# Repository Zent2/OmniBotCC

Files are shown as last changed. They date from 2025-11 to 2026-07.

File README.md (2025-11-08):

# OmniBotCC — Robotat Omnidirectional Agent

**Overview**  
OmniBotCC is a complete project (firmware, MATLAB utilities and Python client) for an **omnidirectional mobile platform** designed to operate inside the **Robotat** ecosystem at the *Universidad del Valle de Guatemala*. The repository provides a reproducible toolset for control experiments, trajectory planning and tracking, simulation, and teaching.

---

## Repository layout (high-level)

- `ESP32/` — ESP32 firmware (ESP-IDF): closed-loop control of 4 stepper motors, AS5600 encoder readings (ADC), per-motor PID and UDP communication.  
- `Funciones_Matlab/` — MATLAB scripts and functions for trajectory planning, Robotat connection, simulation, visualization, calibration and data analysis.  
- `Funciones_Python/` — Python tools and example scripts for sending UDP commands to the ESP32 and quick demos.  
---

## Key features

- Closed-loop PID speed control for four stepper motors (one PID per motor).  
- AS5600 magnetic encoder feedback using ADC for angle and speed estimation.  
- UDP-based command & telemetry over Wi-Fi (integrates with Robotat server).  
- Timer-based step generation with configurable microstepping (example: up to 1/32).  
- FreeRTOS-based multitasking (encoder sampling ISR, PID task, motor control task).  
- MATLAB toolset for trajectory generation, Robotat integration, calibration and post-processing.  
- Python client for quick demos and automation.

---

## System architecture (summary)

**Core components**

- **ESP32 MCU** — main controller: RTOS tasks, PID loops, UDP server.  
- **Stepper drivers** — accept STEP/DIR signals per wheel.  
- **AS5600 encoders** — analog outputs read by ADC for angular position.  
- **PC (MATLAB / Python)** — trajectory planning, visualization and commanding.

**Control loop (stepper motors)**

1. Encoder sampling via timer ISR (example: every 50 ms → 20 Hz).  
2. Compute angular difference → estimate RPM per motor.  
3. PID task computes correction (setpoint vs measured RPM).  
4. Motor control task updates timer parameters and generates STEP pulses.  
5. UDP interface accepts textual commands to change setpoints and states in real time.

### Control loop (Robot)

The closed-loop control for the omnidirectional robot is executed in MATLAB, using real-time feedback from **Robotat** to track the platform’s position and orientation while commanding velocities via UDP.  
The process runs in a control loop with sampling time `dt` (typically 50–100 ms) and includes the following stages:

1. **Pose acquisition (feedback):**  
   The current robot pose (`x_real`, `y_real`, `θ_real`) is obtained from the Robotat system using the function `robotat_get_pose()`.  
   The data is corrected by a known offset and converted to meters and radians.

2. **Goal selection (lookahead target):**  
   The controller selects the next goal point along the trajectory using a *lookahead distance* criterion.  
   This ensures smooth progression between waypoints and avoids oscillations when the robot is close to intermediate targets.

3. **Error computation:**  
   The position and orientation errors are calculated as:  
   \[
   e = \begin{bmatrix} x_g - x \\ y_g - y \\ \theta_g - \theta \end{bmatrix}
   \]
   where \( (x_g, y_g, \theta_g) \) is the current goal pose.  
   These errors drive the PI controller and determine the corrective velocities.

4. **Feedforward + PI control law:**  
   The desired linear and angular velocities are estimated from consecutive points in the trajectory (`v_des`, `w_des`).  
   A **Feedforward + PI** scheme computes the commanded velocity vector in the world frame:
   \[
   \dot{q}_{world} = \dot{q}_{d,world} + K_p e + K_i \int e\,dt
   \]
   where `Kp` and `Ki` are tuned empirically.  
   Integrator limits prevent windup (`I_min`, `I_max`).

5. **Transformation to body frame:**  
   The commanded velocities are converted from the world frame to the robot’s local frame using the current orientation `θ`:
   \[
   v_{body} = R(θ)^T \begin{bmatrix} v_x \\ v_y \end{bmatrix}
   \]
   forming the body velocity vector:
   \[
   V_b = \begin{bmatrix} ω \\ v_{bx} \\ v_{by} \end{bmatrix}
   \]

6. **Wheel speed conversion and saturation:**  
   Wheel angular velocities are obtained via:
   \[
   ω_{wheels} = \frac{1}{r} H_0 V_b
   \]
   where `r` is the wheel radius and `H₀` the kinematic matrix of the omnidirectional platform.  
   These are converted to RPM and limited by `rpm_max`.  
   If saturation occurs, the integrator is frozen (anti-windup).

7. **Command transmission (actuation):**  
   The computed wheel RPMs are sent to the physical robot via the UDP interface using:
   ```matlab
   robot_set_velocities(u_rpm);

---

## Example UDP commands

- `start` — enable all motors  
- `stop` — disable all motors  
- `m0_rpm=250` — set motor 0 target to 250 RPM  
- `m1_dir=CW` / `m1_dir=CCW` — set motor 1 direction  
- `m2_start` / `m3_stop` — control individual motors

---

## Default hardware configuration (example)

**Pin mapping (example)**

| Component | GPIOs | Notes |
|---|---:|---|
| Enable (drivers) | 23 | Shared enable for all drivers |
| STEP (m0..m3) | 26, 19, 16, 14 | Step pulses for motors 0–3 |
| DIR (m0..m3) | 25, 18, 4, 27 | Direction pins for motors 0–3 |
| AS5600 ADC inputs | 34, 35, 32, 33 | Analog encoder inputs |
| Wi-Fi status LED | 2 | Connection status indicator |

**Motor parameters (examples)**

- Steps per revolution: 200  
- Microstepping: 1/32 (configurable)  
- Approx. maximum RPM: ~400  
- Example PID starting gains (tune on hardware): `Kp = 0.04, Ki = 0.002, Kd = 0.0002`
---

## Build & flash (firmware)

1. Install ESP-IDF toolchain (recommended: ESP-IDF v5.x). Follow Espressif's official instructions.  
2. Clone this repository.  
3. From the `firmware/` folder run:

```bash
idf.py set-target esp32
idf.py build
idf.py flash
idf.py monitor
```

---

## MATLAB overview

The `matlab/` folder contains:

- Robotat connection utilities (`robotat_connect`, `robotat_get_pose`, etc.).
- Calibration and quick-start scripts (`Calibracion_Robot.m`, `Inicio_Rapido.m`).  
- Trajectory generators and visualization scripts (`Trayectoria_Omnidireccional.m`, `Trayectorias_Mapa.m`).  
- Utilities for pose conversions and data logging.

Use `Inicio_Rapido.m` to start experiments and `Trayectoria_Omnidireccional.m` for trajectory execution and analysis.

---

## Python client

The `python/` folder includes:

- `Inicio_Rapido.py` — demo routines with connect, set velocities, start/stop and example motion sequences.  
- `udp_robot.py` — helper functions: `robot_connect`, `robot_disconnect`, `robot_start`, `robot_stop`, `robot_set_velocities`.  

Requirements: Python 3.8+, `numpy` (see `requirements.txt`).

---

## License & attribution

This project is property of **Universidad del Valle de Guatemala**. Contact them for licensing and distribution permissions.

---

## Author

**Author:** Christian Campos  
**Institution:** Universidad del Valle de Guatemala

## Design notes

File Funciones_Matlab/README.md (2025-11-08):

# <span style="color:rgb(213,80,0)">OmniBotCC – MATLAB Project Documentation</span>

This Live Script provides an overview of the **OmniBotCC** MATLAB environment,

used for trajectory generation, robot control, and pose tracking with

the **Robotat** motion capture system.

The project communicates with an omnidirectional mobile robot equipped

with a ESP32 microcontroller and integrates MATLAB for simulation, closed loop control,

trajectory planning and performance evaluation.

**Author**: Christian Campos

**Date:** October 2025  

# Project Overview

This MATLAB workspace contains all the scripts and functions needed for:

-   Establishing communication with the omnidirectional robot via Wi-Fi. 
-   Tracking and recording the robot’s pose using the Robotat system. 
-   Generating and executing pre-defined and planed trajectories. 
-   Visualizing, calibrating, and analyzing system performance. 

 The workflow typically follows this sequence:

1.   Connection.
2. Trajectory Generation
3. Trajectory Execution or Marker Tracking in closed loop
4. Data Visualization and Error Analysis

#  Directory Structure

 | `/Simulaciones` | Folder | Simulation models and test scenarios |

 | `/slprj` | Folder | Auto-generated Simulink project files |

 | `Calibracion_Robot.m` | Script | Calibrates the robot’s position and angle (yaw) |

 | `genmap.m` | Script | Generates a Robotat map for trajectory planning |

 | `Inicio_Rapido.m` | Script | Quick Start |

  | `Offsets.mat` | Data | Pre-saved position offsets from Robotat calibration |

  | `q2eul.m`, `q2rot.m` | Functions | Convert quaternions to Euler angles or rotation matrices |

 | `robotat_connect.m` | Function | Connects to the Robotat motion capture server |

 | `robotat_disconnect.m` | Function | Ends connection with Robotat |

 | `robotat_get_pose.m` | Function | Retrieves the current robot pose from Robotat |

 | `robotat_trvisualize.m` | Function | Visualizes rigid bodies within the Robotat reference frame |

 | `robot_connect.m` | Function | Establishes communication with the robot controller |

 | `robot_disconnect.m` | Function | Closes communication with the robot |

 | `robot_emergency_stop.m` | Function | Immediately halts robot movement |

 | `robot_send_WiFi.m` | Function | Sends data packets to the robot over Wi-Fi |

 | `robot_set_ustep.m` | Function | Sets the microstepping configuration for motors | (NOT USED)

 | `robot_set_velocities.m` | Function | Sends velocity commands to each wheel |

 | `robot_start.m` / `robot_stop.m` | Functions | Start/stop robot motion commands |

 | `Trayectoria_Omnidireccional.m` | Script | Omnidirectional trajectory generation and execution module |

 | `Trayectorias_Mapa.m` | Script | Builds and visualizes a trajetory over a map with obstacles|

 | `Seguimiento_marcador.m` | Script | Follow a markers' position |

#  Simulation Environment

 The `/Simulaciones` folder includes models and scripts for testing

 the robot control algorithms in a simulated environment before

 applying them to the real hardware.

#  License

 This project is property of Universidad del Valle de Guatemala.

```matlab
mdfile = export("README.mlx",Format="markdown")
```

```TextOutput
mdfile = 'C:\Users\chris\OneDrive - UVG\UVG-ChrisLaptop\Proyecto de Graduacion-Tesis\Carpeta Final\Funciones_Matlab\README.md'
```

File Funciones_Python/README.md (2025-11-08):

# OmniBotCC (Python)

Example project to control an OmniBotCC robot over UDP (ESP32) and demonstrate mapping body velocities to wheel RPMs.

## Repository contents
- `Inicio Rapido.py`  
    Main script with two demos:
    - `simple_demo()` — basic commands (connect, set velocities, start/stop, disconnect) and a sequential RPM motion routine.
    - `vb_demo()` — maps body velocities Vb = [omega, vx, vy] to the 4-wheel RPMs using matrix H0 and controls the robot via UDP.
- `udp_robot.py`  
    UDP module with functions:
    - `robot_connect()` — creates a UDP socket and configures the ESP32 IP/port.
    - `robot_disconnect()` — closes the socket.
    - `robot_start()` / `robot_stop()` — sends `start`/`stop` commands.
    - `robot_set_velocities(rpm_vector)` — sends direction and RPM per motor (`m{i}_dir`, `m{i}_rpm`).
- `robotat.py`  
    Simple TCP connection example (placeholder) with:
    - `robotat_connect()` — attempts a TCP connection to a host/port.
    - `robotat_disconnect(tcp_obj)` — closes the TCP connection.

## Requirements
- Python 3.8+
- numpy
- Standard modules: socket, time, math

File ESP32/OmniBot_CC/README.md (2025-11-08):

# Robotat Omnidirectional Agent (OmniBotCC)

## Overview
**OmniBotCC** is an embedded control application developed using the **ESP-IDF framework** for the **ESP32 microcontroller**. It serves as the main controller for an **omnidirectional robotic agent** within the **Robotat ecosystem** at *Universidad del Valle de Guatemala*.

The system controls **four stepper motors** arranged in an omnidirectional configuration, allowing movement across a 2D plane. Each motor is equipped with an **AS5600 magnetic encoder** for closed-loop feedback, enabling precise **PID speed control**. Communication with the Robotat environment is established via **UDP over Wi-Fi**, allowing external systems (e.g., Robotat server) to send commands and receive updates.

---

## Main Features
- Closed-loop control of four stepper motors using PID.
- High-resolution feedback from AS5600 encoders (ADC-based angle measurement).
- UDP communication for remote control and data exchange.
- Timer-based PWM generation for stepper control (microstepping up to 1/32).
- Wi-Fi initialization with optional LED status indicator.
- Multi-tasking architecture using FreeRTOS:
  - Timer-based periodic callback (20 Hz) for encoder sampling.
  - PID task for closed-loop speed regulation.
  - Motor control task for stepper pulse generation.
- Dynamic command parsing via UDP or UART (optional).
- Robust error handling and logging through ESP-IDF’s `esp_log`.

---

## System Architecture

### Core Components
| Component | Description |
|---|---|
| ESP32 MCU | Central controller executing FreeRTOS tasks and PID loops. |
| Stepper Drivers | Receive STEP/DIR signals for motion control. |
| AS5600 Encoders | Provide analog angular position feedback for speed estimation. |
| Wi-Fi UDP Server | Handles incoming motion and configuration commands. |
| PID Controller | Regulates motor speed using feedback from encoders. |

---

## Control Loop Description

1. **Encoder Sampling (Timer ISR)**  
   The system periodically reads angular positions from the AS5600 sensors every **50 ms (20 Hz)**.  
   Angular differences are converted into estimated RPM values per motor.

2. **PID Task**  
   The PID controller compares desired RPM vs. measured RPM to compute a control signal.  
   The signal adjusts the timer parameters that generate motor steps.

3. **UDP Command Interface**  
   Commands are received as strings through UDP packets. Examples include:
start
stop
m0_rpm=200
m1_dir=CCW
m2_start
m3_stop

Commands dynamically update the control parameters in real time.

4. **Motor Control**  
Each motor runs in closed-loop mode, maintaining its target speed with high precision.

---

## Command Examples

| Command | Description |
|---|---|
| `start` | Enables all motors. |
| `stop` | Disables all motors. |
| `m0_rpm=250` | Sets motor 0 to 250 RPM. |
| `m1_dir=CW` / `m1_dir=CCW` | Sets direction of motor 1. |
| `m2_start` | Activates motor 2 only. |
| `m3_stop` | Stops motor 3 only. |

---

## File Structure

```
OmniRobot_CC/
├─ platformio.ini
├─ README.md
├─ docs/
│  ├─ overview.md
│  └─ wiring.md
├─ firmware/
│  ├─ src/
│  │  ├─ main.cpp
│  │  ├─ MotorController.cpp
│  │  ├─ MotorController.h
│  │  ├─ PID.cpp
│  │  ├─ PID.h
│  │  ├─ AS5600.cpp
│  │  ├─ AS5600.h
│  │  ├─ WiFiManager.cpp
│  │  ├─ WiFiManager.h
│  │  ├─ WebServer.cpp
│  │  └─ config.h
│  ├─ lib/
│  └─ include/
├─ hardware/
│  ├─ schematics/
│  └─ pcb/
├─ tools/
│  ├─ calibrate.py
│  └─ bench_tests/
├─ data/
│  └─ spiffs/
├─ examples/
└─ releases/
    └─ firmware_v1.0.bin
```

---

## Hardware Configuration

### Pinout Summary
| Component | GPIOs | Description |
|---|---|---|
| Enable | 23 | Shared enable pin for all drivers |
| Stepper STEP Pins | 26, 19, 16, 14 | Pulse control for motors 0–3 |
| Stepper DIR Pins | 25, 18, 4, 27 | Direction control for motors 0–3 |
| AS5600 Inputs | 34, 35, 32, 33 | ADC inputs for encoder readings |
| LED (Wi-Fi) | 2 | Status indicator for Wi-Fi connection |

### Motor Parameters
- Steps per revolution: 200  
- Microstepping: 1/32  
- Maximum RPM: 400  
- PID gains (tunable):
Kp = 0.04
Ki = 0.002
Kd = 0.0002

---

## Build and Flash Instructions

1. **Set up ESP-IDF (v5.x)** following the official [ESP-IDF documentation](https://docs.espressif.com/).
2. Clone this repository.
3. Build the firmware: idf.py build
4. Flash the ESP32: idf.py flash
5. Monitor before using: idf.py monitor

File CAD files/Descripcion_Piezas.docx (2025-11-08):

Estas son las piezas del prototipo, por lo que los colores si importan (menos los que dicen preferiblemente). El color azul y el verde pino fueron colocados dentro de las compras de materiales del departamento.

Pieza | Descripción

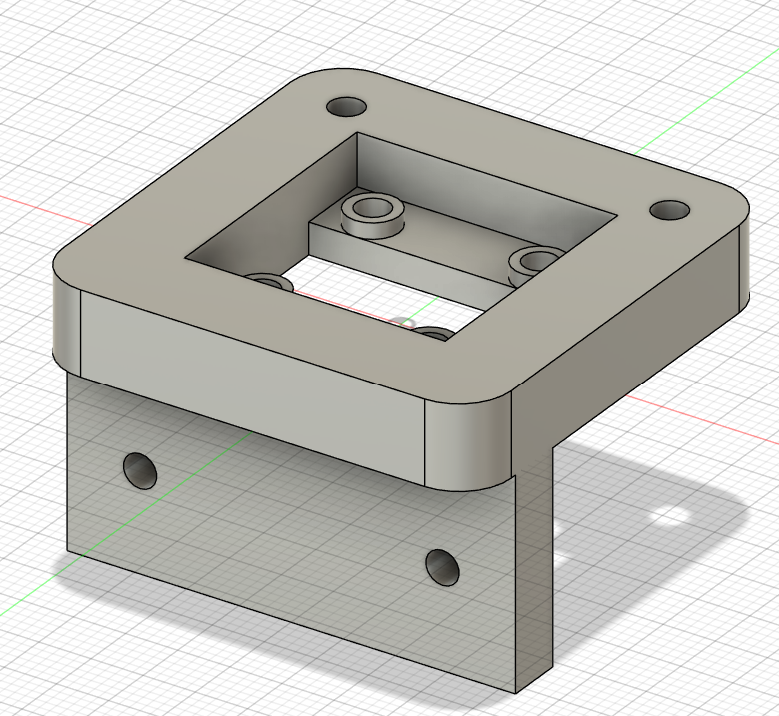
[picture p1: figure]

| Soporte AS5600_R_x2: Color: Negro (preferiblemente) Dimensiones Generales: 28x43x34 en mm Agujeros: 3 mm

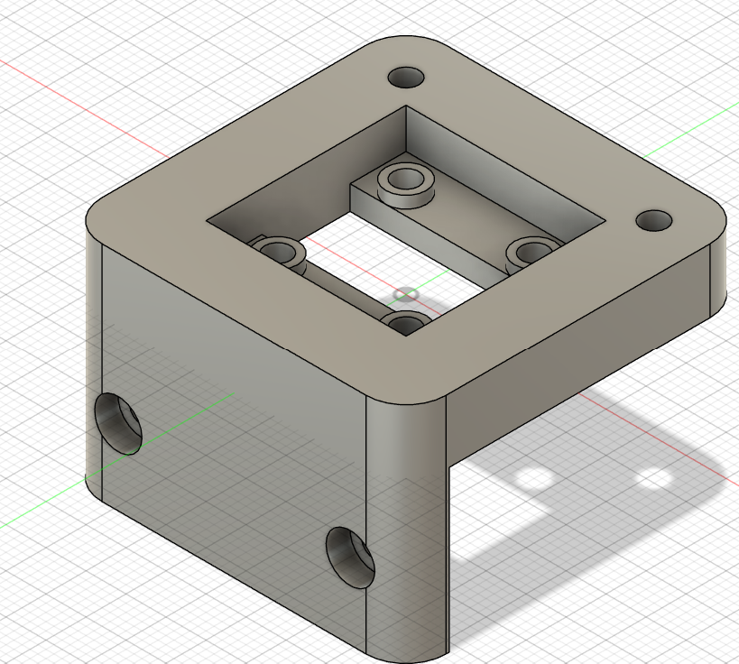
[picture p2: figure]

| Soporte AS5600_L_x2: Color: Negro (preferiblemente) Dimensiones Generales: 28x43x34 en mm Agujeros: 3 mm

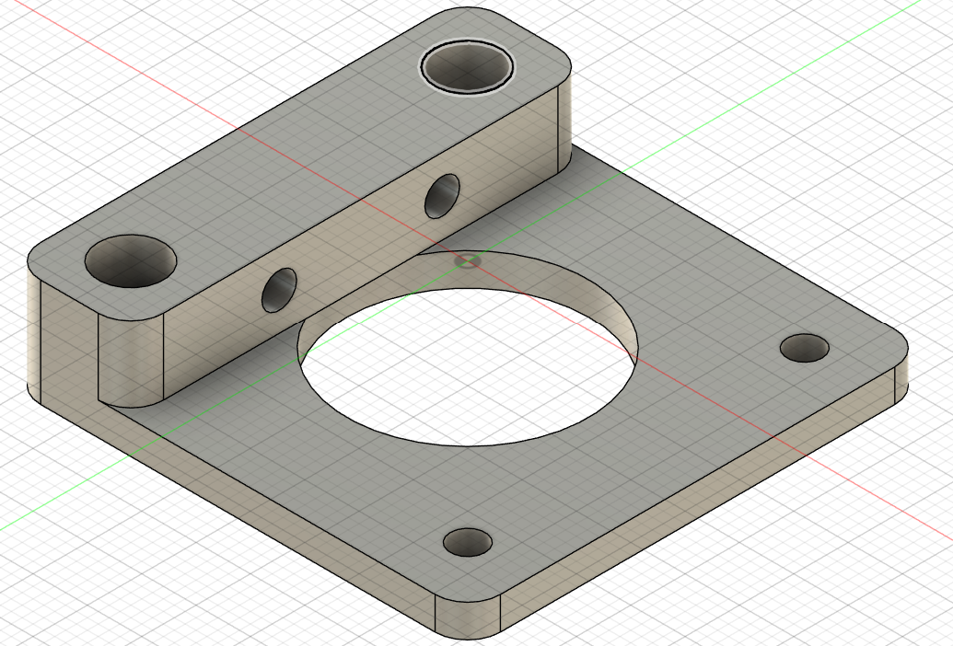
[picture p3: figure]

| Base_Motor_x4: Color: Negro (preferiblemente) Dimensiones: 42.3x42.3x10(3) en mm Agujeros: 3mm

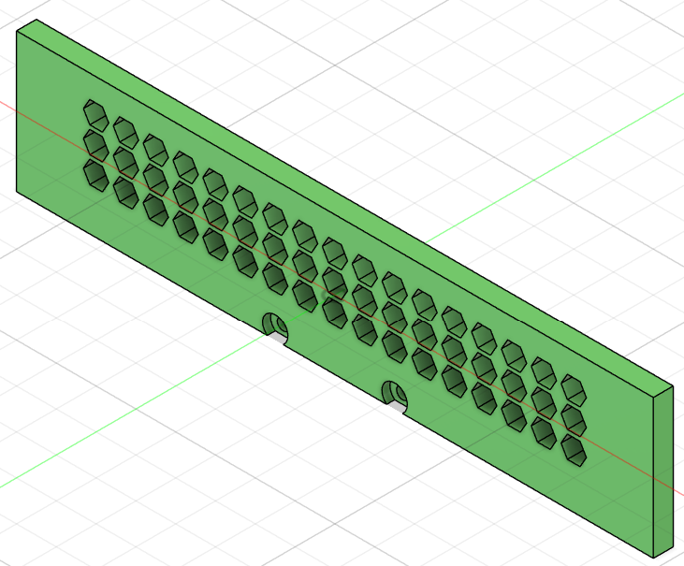
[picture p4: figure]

| Nivel_1_Paredes_x2: Color: Verde Pino Dimensiones Generales: 160x35x5 en mm Agujeros: 3 mm

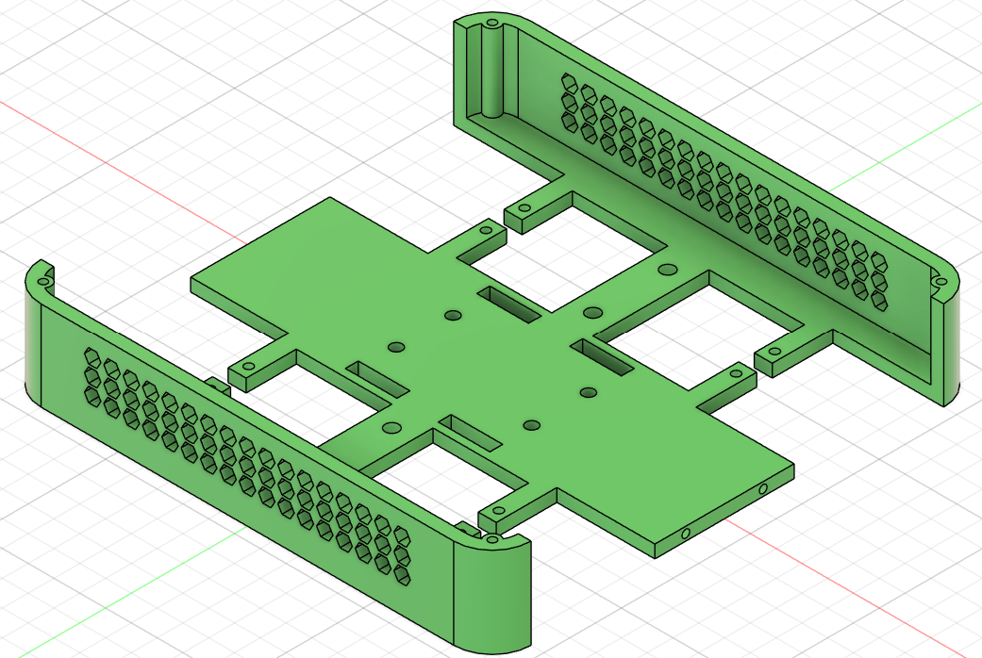
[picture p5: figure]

| Nivel_1_Base: Color: Verde Pino Dimensiones Generales: 190x190x35 en mm Agujeros: 3 mm y 5 mm

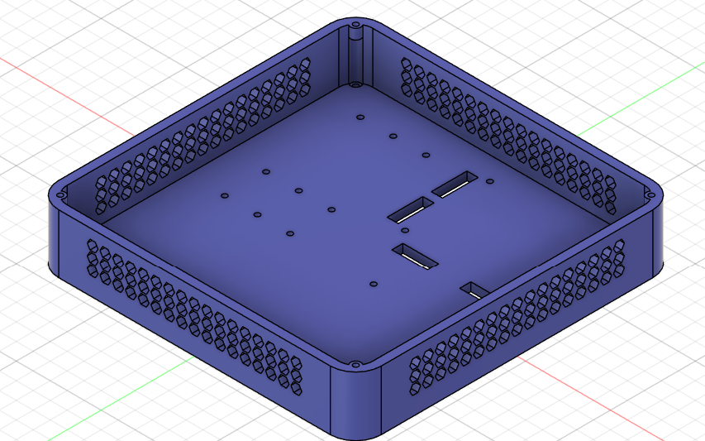
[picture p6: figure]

| Nivel2: Color: Azul Dimensiones Generales: 190x190x35 en mm Agujeros: 3 mm

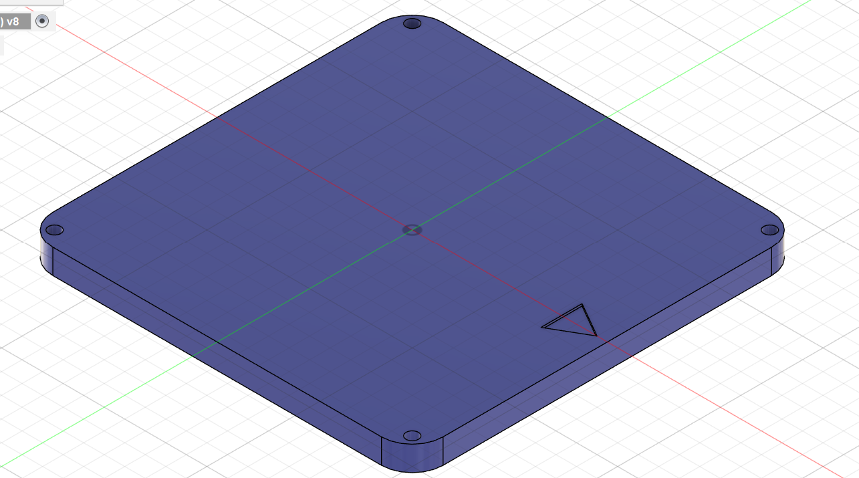
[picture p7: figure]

| Nivel 3: Color: Azul Dimensiones Generales: 190x190x12 en mm Agujeros: 3 mm El Triangulo no es tan profundo, no debería ser necesario el soporte.

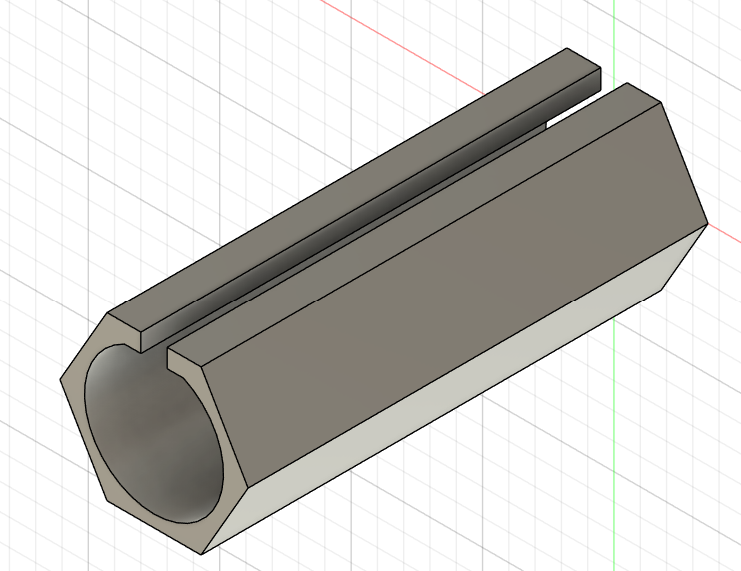
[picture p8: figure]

| Eje_Llanta_x4: Color: Negro (preferiblemente) Hexágono: 6.2x6.2mm Diámetro agujero: 5.10mm Esto hace las paredes muy delgadas, aproximadamente 0.6mm. Yo al imprimirlos los imprimi acostados como en la imagen.

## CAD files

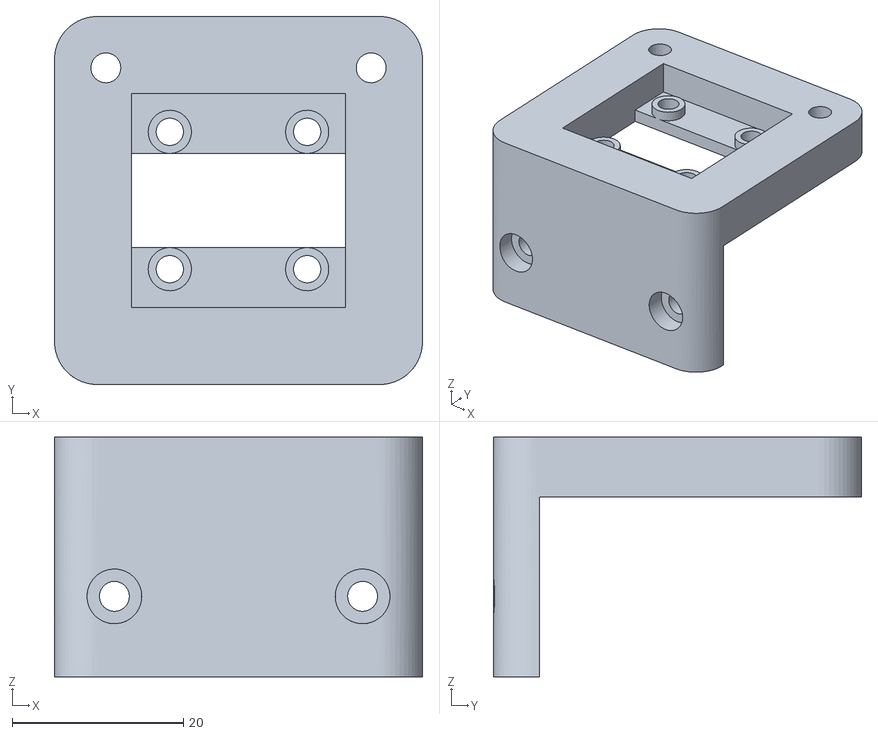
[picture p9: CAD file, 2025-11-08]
CAD files/Soporte_AS5600_L_x2.stl
43.0 x 43.0 x 28.0

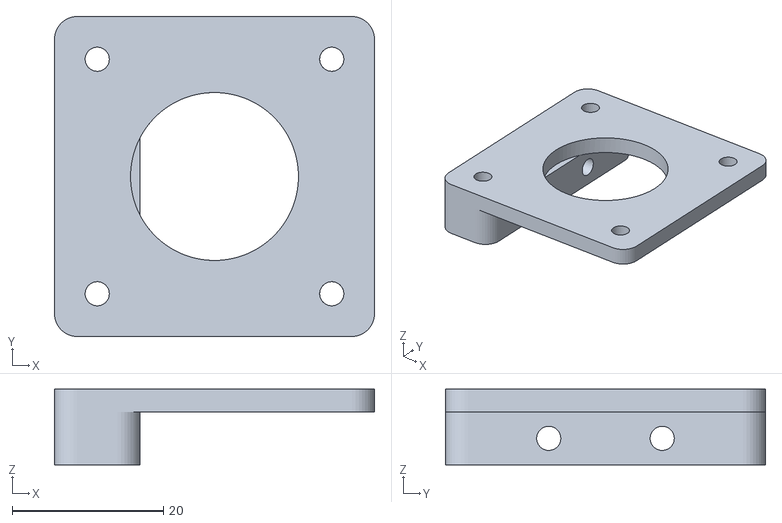
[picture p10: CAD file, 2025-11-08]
CAD files/Base_Motor_x4.stl
42.3 x 42.3 x 10.0

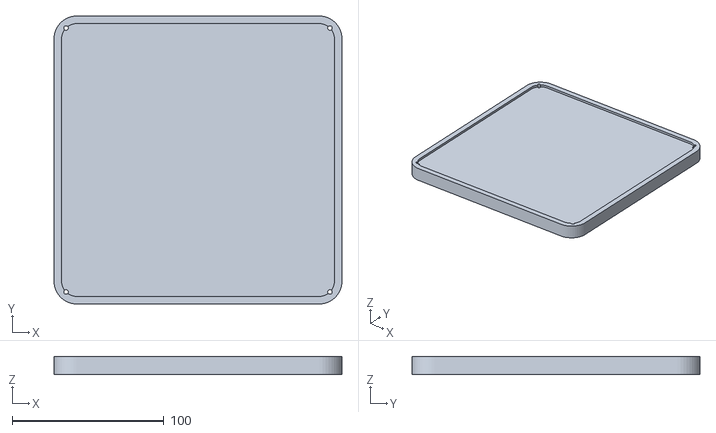
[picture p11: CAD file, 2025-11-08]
CAD files/Nivel3.stl
190.0 x 190.0 x 12.0

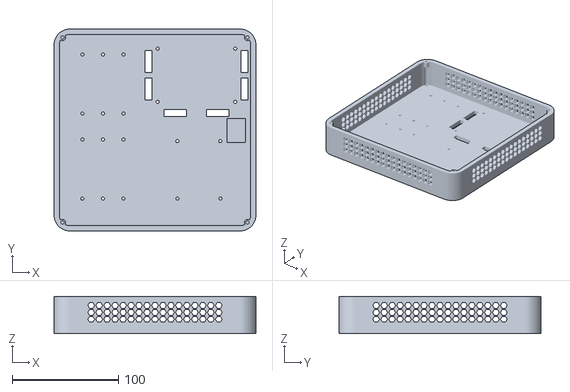
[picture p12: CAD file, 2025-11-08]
CAD files/Nivel2.stl
190.0 x 190.0 x 35.0

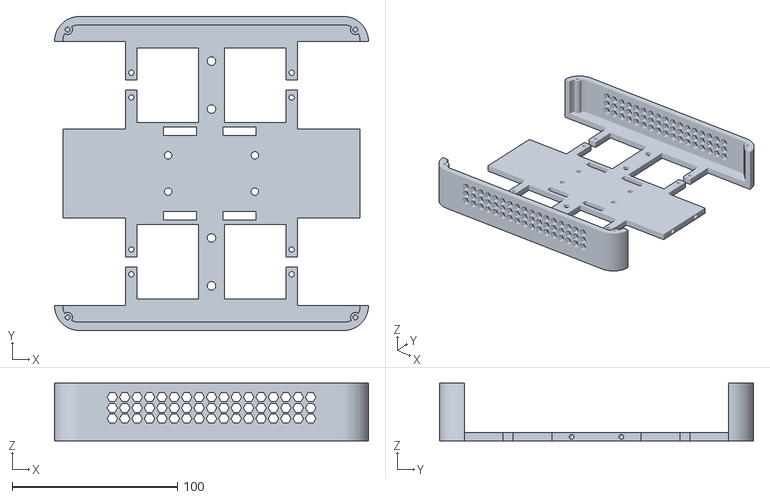
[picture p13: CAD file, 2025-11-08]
CAD files/Nivel1_Base.stl
190.0 x 190.0 x 35.0

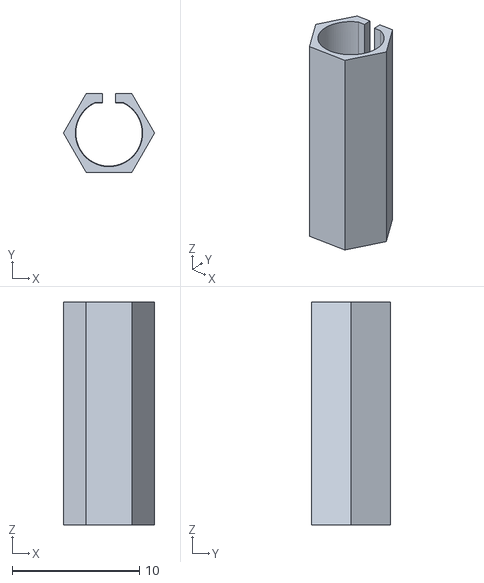
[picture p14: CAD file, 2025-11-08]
CAD files/Eje_Llanta_x4.stl
7.16 x 6.20 x 17.5

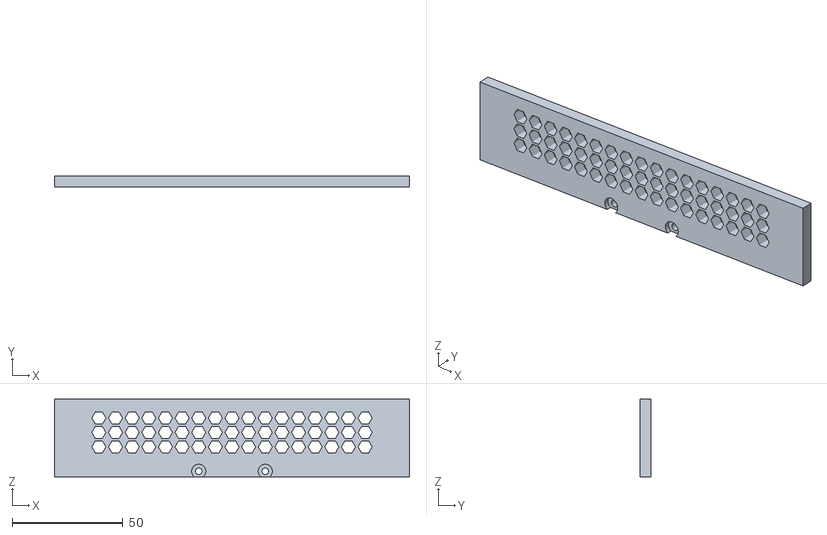
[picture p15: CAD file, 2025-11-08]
CAD files/Nivel1_Pared_x2.stl
160.0 x 5.00 x 35.0

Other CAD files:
CAD files/Soporte_AS5600_R_x2.stl

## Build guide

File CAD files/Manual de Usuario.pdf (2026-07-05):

Universidad del Valle de Guatemala | 2025

# OmniBotCC: Manual de usuario

### Christian Campos

### 8 de noviembre de 2025

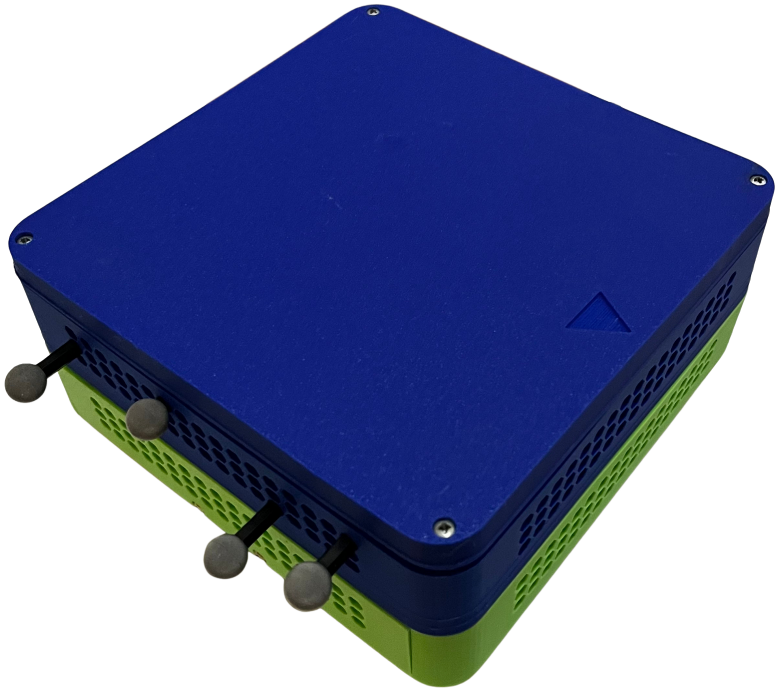
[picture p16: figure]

OmniBotCC - Manual de Construcción Versión 1.0 (2025)
© 2025 Universidad del Valle de Guatemala. Departamento de Ingeniería Electrónica, Mecatrónica y Biomédica. Este manual cubre el ensamblaje mecánico y las conexiones eléctricas básicas. Fabricado en Guatemala.

Universidad del Valle de Guatemala | 2025

## Índice

1. Descripción general: ¿Qué es el OmniBotCC? | 3
2. Requisitos y seguridad | 4
3. Listado de Materiales (BOM) | 6
4. Hardware | 8
5. Software/Firmware | 20
6. Calibración y mantenimiento | 24
7. Especificaciones técnicas | 26
8. Soporte y licencias | 27

Universidad del Valle de Guatemala | 2025

## 1. Descripción general: ¿Qué es el OmniBotCC?

El OmniBotCC es un robot móvil de 190mm de largo y ancho versátil, de alto desempeño y precisión. El OmnbiBotCC fue diseñado para funcionar como una plataforma móvil complementaria para otros agentes robóticos. Por lo mismo, fue construído con un enfoque omnidireccional, usando ruedas Mecanum de 45° grados. El corazón de este robot es un microcontrolador ESP32 (https://www.espressif.com/en/products/socs/esp32) desarrollado por Espressif. Para programarlo es necesario contar con una computadora con el entorno de desarrollo oficial de Espressif, ESP-IDF, y un cable micro usb.

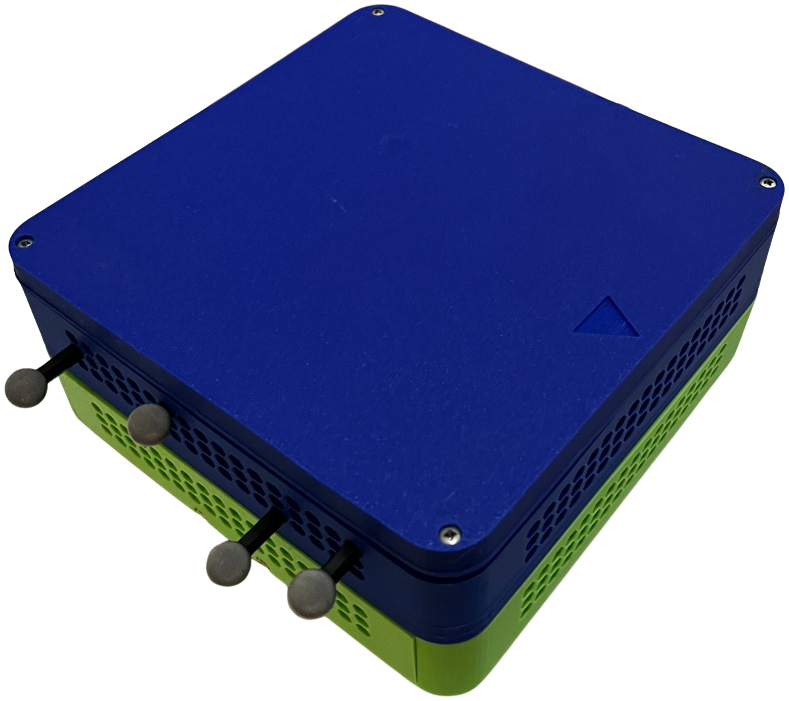
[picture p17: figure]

El OmniBotCC cuenta con 4 ruedas Mecanum (https://oxdea.gt/product/par-de-llantas-omnidireccionales-de-48-mm) de 45° grados con motores paso a paso Nema 17 (https://laelectronica.com.gt/motor-de-pasos-nema-17-de-23mm) de 23mm de grosor. Estos son controlados en lazo cerrado a través de un sistema de controladores DRV8825 (https://www.ti.com/lit/ds/symlink/drv8825.pdf) o TMC2209 (https://www.analog.com/media/en/technical-documentation/data-sheets/tmc2209_datasheet_rev1.09.pdf) y un sensor magnético de posición AS5600. (https://files.seeedstudio.com/wiki/Grove-12-bit-Magnetic-Rotary-Position-Sensor-AS5600/res/Magnetic%20Rotary%20Position%20Sensor%20AS5600%20Datasheet.pdf) Así mismo, tanto el microcontrolador como los motores están alimentados a través de 6 baterías 18650, (https://www.alldatasheet.com/html-pdf/1492277/SAMSUNG/ICR18650/343/1/ICR18650.html) con una conexión de 3 celdas en serie y 2 celdas en paralelo (12.6V). La carga y descarga está controlada por un BMS (https://www.mantech.co.za/datasheets/products/BMS-20A-3S-S_SGT.pdf) y el voltaje de entrada para el microcontrolador y los motores son reguladas por 2 diferentes reguladores de voltaje.

Universidad del Valle de Guatemala | 2025

## 2. Requisitos y seguridad

### 2.1. Requisitos mínimos del equipo

Para operar la plataforma OmniBotCC se necesita:

Un computador con MATLAB o Python (versión recomendada: Python 3.8+ / MATLAB R2021a o superior).

Red Wi-Fi (AP) con capacidad para comunicación UDP entre el computador y el ESP32.

Fuente de alimentación y cargador para el BMS con el pack de baterías. Esta fuente de alimentación debe ser capaz de otorgar 12.6V@2.6A durante 3 horas para carga normal y 12.6V@5.2A para carga rápida durante 2.5 horas.

Herramientas básicas: destornilladores, llave hexagonal, multímetro y pinzas.

Impresora 3D (si se van a fabricar las piezas) con volumen de impresión mínimo de 190mmx190mm listo para las piezas del chasis.

### Precauciones de seguridad

Para garantizar la seguridad del usuario y de la plataforma móvil se deben seguir estas indicaciones:

Baterías: Las 18650 son celdas de ion-litio. Por lo que es indispensable evitar cortocircuitos, no dejarlas caer, cargarlas siempre a través de un cargador balanceador (BMS) y no sobrecargarlas ni las descargarlas por debajo de 2.8V por celda.

Conexión y prueba de motores: Las primeras pruebas deben realizarse con el chasis asegurado y con las ruedas libres de contacto. Además, de emplear un modo de baja velocidad para estas pruebas.

Manipulación de PCBs: Debe evitarse conectar las placas PCB si se nota: estática, soldaduras frías visibles o componentes sueltos.

Entorno de pruebas: Se debe trabajar en un espacio despejado. Manteniendo personas y objetos frágiles fuera del área de prueba.

Firmware: Antes de subir firmware nuevo es importante verificar que los límites de velocidad estén probados para evitar comportamientos inesperados. Velocidades muy altas podrían provocar: sobrecalentamiento, resonancia, vibraciones muy altas y campos magnéticos no deseados.

Controladores: Antes de comenzar con cualquier tipo de pruebas, es requerimiento calibrar correctamente el amperaje máximo de los controladores de los motores.

Ensamblado: Antes de cualquier prueba, se debe verificar que todo el ensamblado se haya realizado correctamente.

### Señales de advertencia y qué hacer

Olor a quemado o humo: Se debe apagar inmediatamente la alimentación general. Se deben inspeccionar las PCBs, buscando la fuente del humo o el olor. Si fueran las baterías, inmediatamente se deben desconectar y verificar que no haya habido corto. Recuerde que las baterías de Li-Ion son muy inestables y pueden llegar a incendiarse o incluso explotar.

Universidad del Valle de Guatemala | 2025

Vibraciones o ruidos inusuales: Debe pararse la plataforma y revisar el montaje mecánico y los acoplamientos de los motores. También debe verificarse que el entorno de trabajo sea el adecuado. La plataforma móvil está diseñada exclusivamente para moverse en superficies planas y sin ningún tipo de variaciones en el terreno.

Temperaturas altas (>,70°C) en controladores o motores: Debe detenerse la prueba y dejar enfriar. A pesar que los controladores tienen disipadores de calor, el uso muy extenso de la plataforma móvil puede llevar a sobrecalentamiento.

Universidad del Valle de Guatemala | 2025

## 3. Listado de Materiales (BOM)

Los materiales necesarios para la construcción del OmniBotCC están descritos en el siguiente cuadro. Debe tomarse en cuenta que los distribuidores fueron consultados el 27 de agosto del 2025. Así mismo, los distribuidores son todos del país de Guatemala, si usted se encuentra afuera del país puede usar los enlaces como referencia.

Componente | Cantidad | Distribuidor
Nema 17 23mm | 4 | LaElectrónica (https://laelectronica.com.gt/motor-de-pasos-nema-17-de-23mm?search=NEMA17&description=true)
Ruedas Mecanum (par L-R) | 2 | Oxdea (https://oxdea.gt/product/par-de-llantas-omnidireccionales-de-48-mm/)
Material PLA (Por Kg) | 0.50368 | Creativo3D (https://www.creativo3d.com/product/esun-pla-premium-de-alta-velocidad-1-0-kg-1-75mm-filamento-pla-25-colores-diferentes/)
Regulador de Voltaje (300W) | 1 | LaElectrónica (https://laelectronica.com.gt/modulo-regulador-de-voltaje-con-limite-de-corriente-cc-cv---20a)
Regulador de Voltaje 5V | 1 | LaElectrónica (https://laelectronica.com.gt/modulo-regulador-de-voltaje-de-5v-3a)
AS5600 | 4 | Oxdea (https://oxdea.gt/product/sensor-de-medicion-de-angulo-por-induccion-magnetica-de-12-bits-as5600/)
Cables JST XH Hembra (6 a 4 pines) | 4 | LaElectrónica (https://laelectronica.com.gt/cable-xh254-de-15-m-para-nema-17)
Cable Calibre 14 (Por metro) | 2 | LaElectrónica (https://laelectronica.com.gt/cable-para-bocina-calibre-14)
Tira de Bornera (6Pines) | 1 | LaElectrónica (https://laelectronica.com.gt/conexiones/borneras/tira-de-bornera-de-hierro-de-5-contactos-y-15a)
Jumpers Hembra-Macho 20cm (x10) | 1 | LaElectrónica (https://laelectronica.com.gt/jumper-20-cm-mxf-20-piezas)
Jack Banana Hembra | 2 | Tettsa (https://tienda.tettsa.gt/producto/bornera-chasis-roja-10x32mm)
Placa Alimentación (15x20 cm, referencia) | 1 | MakerLab/LaElectrónica (https://laelectronica.com.gt/pcb/placas-de-cobre-y-fibra-de-vidrio/placa-de-cobre-15x20-cm)
BMS (3s 20a) | 1 | Oxdea (https://oxdea.gt/product/placa-de-proteccion-de-bateria-bms-12-6v-3s-20a/)
Baterías 18650 | 6 | LaElectrónica (https://laelectronica.com.gt/bateria-li-ion-18650-lishen-lr18650sk-de-2600-mah-2c)
Sujetador bat. PCB 3s | 2 | LaElectrónica (https://laelectronica.com.gt/sujetador-de-3-baterias-18650-para-pcb)
Placa Control (7x10 cm, referencia) | 1 | MakerLab/LaElectrónica (https://laelectronica.com.gt/pcb/placas-de-cobre-y-fibra-de-vidrio/placa-de-cobre-de-doble-cara-de-7x10-cm)
ESP32 | 1 | LaElectrónica (https://laelectronica.com.gt/modulo-wifi-bluetooth-esp32-ch340?search=esp32&description=true)
DRV8825 (Driver Paso a Paso) | 4 | LaElectrónica (https://laelectronica.com.gt/driver-drv8825-para-motor-stepper)
Header Hembra (40 pines) | 1 | Tettsa (https://tienda.tettsa.gt/producto/header-hembra-40-pin-2-54mm-tira-simple)
Header Hembra (8 pines) | 9 | Tettsa (https://tienda.tettsa.gt/producto/headers-hembra-8-pines-2-54mm)
Conector Macho 4 pines | 4 | LaElectrónica (https://laelectronica.com.gt/conector-macho-a-placa-xh-4a-4-pines)
Switch | 1 | Tettsa (https://tienda.tettsa.gt/producto/mini-switch-rocker-2-pin-on-off-6a-125vac)
Bornera 15A | 2 | LaElectrónica (https://laelectronica.com.gt/bornera-2-pines-250-v-a-15-a)
Tornillos M3x8 Allen | 4 | La Casa del Tornillo (https://casator.com/)
Tornillos M3x8 Planos Phillips | 12 | La Casa del Tornillo (https://casator.com/)
Tornillos M3x8 Redonda Phillips | 40 | La Casa del Tornillo (https://casator.com/)
Tornillos M3x12 Planos Phillips | 12 | La Casa del Tornillo (https://casator.com/)
Tornillos M3x12 Redonda Phillips | 12 | La Casa del Tornillo (https://casator.com/)
Tornillos M3x16 Redonda Phillips | 4 | La Casa del Tornillo (https://casator.com/)
Tornillos M3x25 Planos Phillips | 8 | La Casa del Tornillo (https://casator.com/)
Tuercas M3 | 44 | La Casa del Tornillo (https://casator.com/)

Universidad del Valle de Guatemala | 2025
Material | Precio Unitario | Cantidad | Precio Total
Nema 17 23mm | Q139.00 | 4 | Q556.00
Ruedas Mecanum (par L-R) | Q99.00 | 2 | Q198.00
Material PLA (Por Kg) | Q175.00 | 0.50368 | Q88.14
Regulador de Voltaje (300W) | Q129.00 | 1 | Q129.00
Regulador de Voltaje 5V | Q27.00 | 1 | Q27.00
AS5600 | Q70.00 | 4 | Q280.00
Cables JST XH Hembra (6 a 4 pines) | Q24.00 | 4 | Q96.00
Cable Calibre 14 (Por metro) | Q4.50 | 2 | Q9.00
Tira de Bornera (6Pines) | Q11.00 | 1 | Q11.00
Jumpers Hembra-Macho 20cm (x10) | Q8.00 | 1 | Q8.00
Jack Banana Hembra | Q4.50 | 2 | Q9.00
Placa Alimentación (referencia) | Q35.00 | 1 | Q35.00
BMS (3s 20a) | Q45.00 | 1 | Q45.00
Baterías 18650 | Q59.00 | 6 | Q354.00
Sujetador bat. PCB 3s | Q19.00 | 2 | Q38.00
Placa Control (referencia) | Q10.00 | 1 | Q10.00
ESP32 | Q125.00 | 1 | Q125.00
DRV8825 (Driver Paso a Paso) | Q38.00 | 4 | Q152.00
Header Hembra (40 pines) | Q4.00 | 1 | Q4.00
Header Hembra (8 pines) | Q3.00 | 9 | Q27.00
Conector Macho 4 pines | Q1.00 | 4 | Q4.00
Switch | Q6.00 | 1 | Q6.00
Bornera 15A | Q2.00 | 2 | Q4.00
Tornillos M3x8 Allen | Q3.53 | 4 | Q14.12
Tornillos M3x8 Planos Phillips | Q1.12 | 12 | Q13.44
Tornillos M3x8 Redonda Phillips | Q1.33 | 40 | Q53.20
Tornillos M3x12 Planos Phillips | Q1.64 | 12 | Q19.68
Tornillos M3x12 Redonda Phillips | Q1.64 | 12 | Q19.68
Tornillos M3x16 Redonda Phillips | Q1.95 | 4 | Q7.80
Tornillos M3x25 Planos Phillips | Q2.65 | 8 | Q21.20
Tuercas M3 | Q1.48 | 44 | Q65.12
Total | | | Q2,429.38

Universidad del Valle de Guatemala | 2025

## 4. Hardware

### 4.1. Visión general

El hardware de la plataforma se compone de tres subsistemas principales:

1. Mecánica: chasis modular impreso en 3D, soportes de motores, ejes y ruedas mecanum.
2. Electrónica de potencia: placa PCB con un pack de baterías 3s2p y un BMS. Así como 2 reguladores de voltaje (5V para el ESP32 y 10V para los motores).
3. Electrónica de control: PCB con el ESP32, controladores de los motores y sensores AS5600.

### 4.2. Pasos a seguir

Para el montaje se deben seguir los siguientes pasos:

1. Imprimir las piezas en PLA, siguiendo las recomendaciones que se encuentran en la Sección 4.3.
2. Ensamblar la plataforma móvil siguiendo las instrucciones en la Sección 4.4.
3. Se instalan las PCBs en su nivel correspondiente y se hacen las conexiones siguiendo los esquemáticos mostrados en la Sección 4.5.
4. Se realizan las pruebas iniciales como se indica en la Sección 4.6

### 4.3. Impresion 3D

Para las piezas del chasis, se requiere de una impresora 3D que tenga un área mínima de impresión de 190mmx190mmx35mm. Los archivos STL se encuentran en el siguiente enlace: GitHub impresión 3D. (https://github.com/Zent2/OmniBotCC/tree/main/3.%20Piezas%20para%20impresion%203D)

Universidad del Valle de Guatemala | 2025

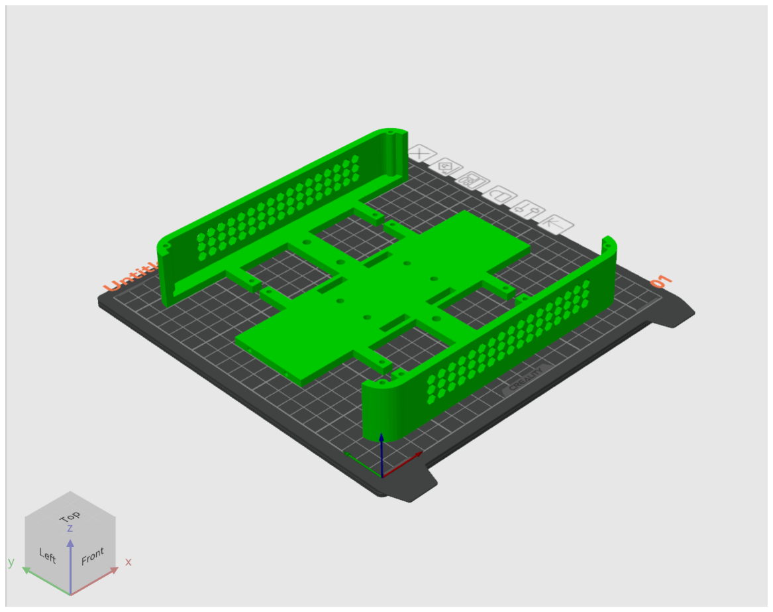
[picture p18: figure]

Nivel 1: En esta pieza se recomienda usar las configuraciones estándar de la impresora. No es necesario agregar soportes, aunque su uso podría mejorar la calidad de la pieza.

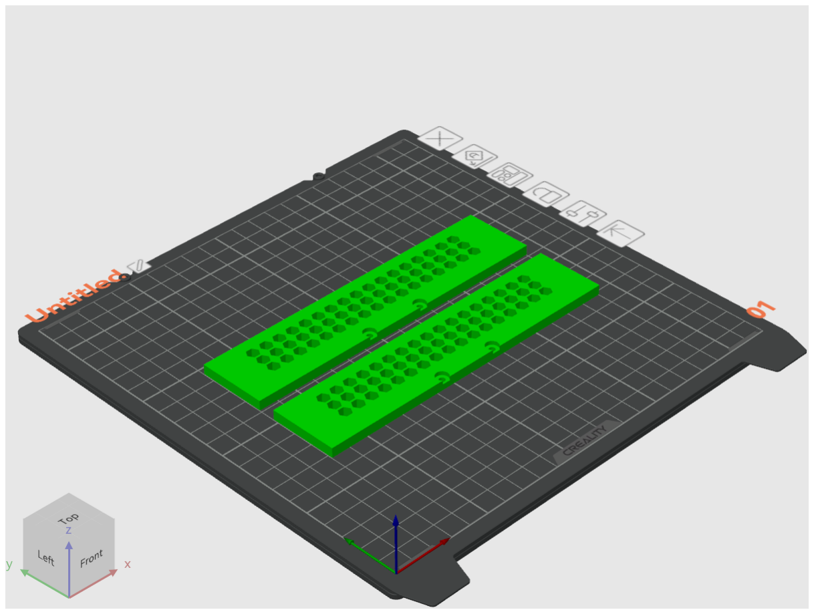
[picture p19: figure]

Nivel 1 (laterales): En estas piezas se recomienda usar las configuraciones estándar de la impresora. No es necesario agregar soportes.

Universidad del Valle de Guatemala | 2025

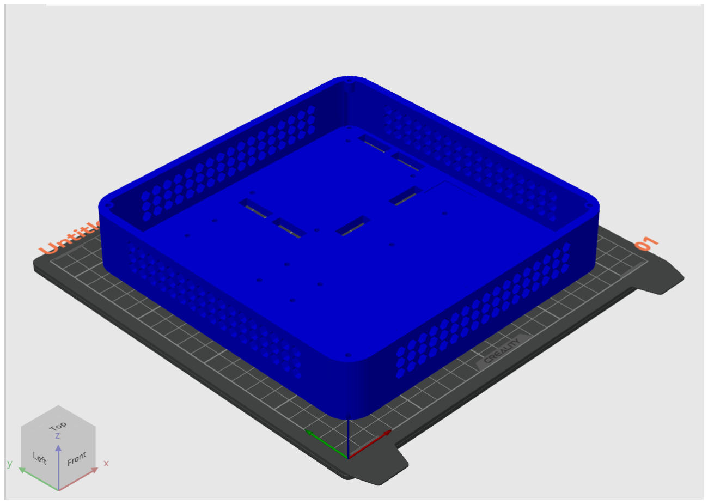
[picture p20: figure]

Nivel 2: En esta pieza se recomienda usar las configuraciones estándar de la impresora. Los soportes recomendados son manuales en los agujeros altos de la pieza.

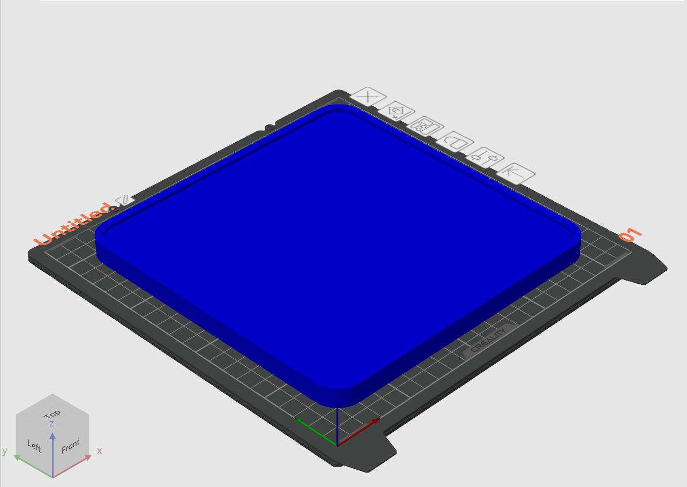
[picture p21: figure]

Nivel 3: En esta pieza se recomienda usar las configuraciones estándar de la impresora. Los soportes deben configurarse de tal manera que sean fáciles de extraer pues el triángulo/flecha mide solo 1mm de profundidad.

Universidad del Valle de Guatemala | 2025

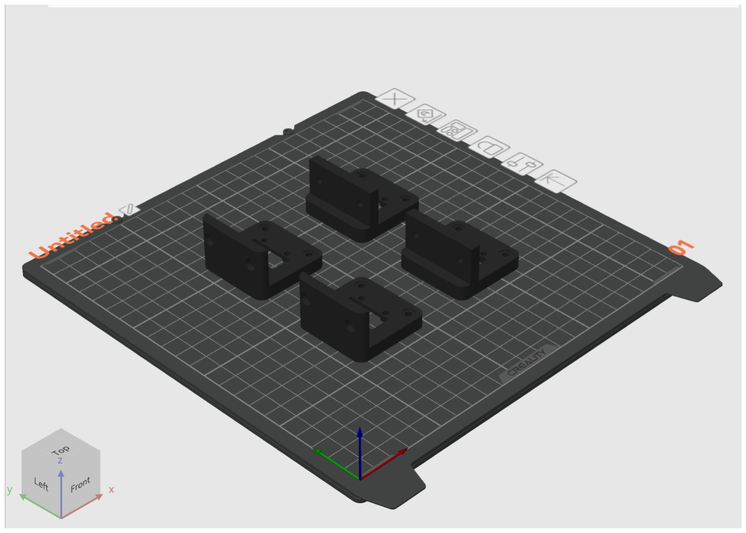
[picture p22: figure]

Soportes AS5600 (izquierda y abajo): En estas piezas se recomienda usar las configuraciones estándar de la impresora. Los soportes son requeridos.

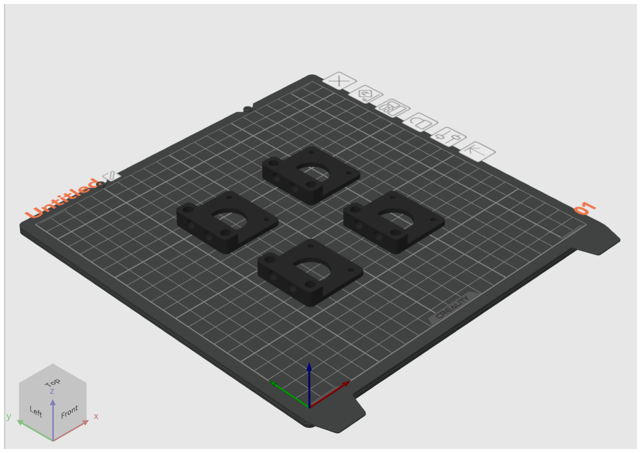
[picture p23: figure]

Bases para los motores: En estas piezas se recomienda usar las configuraciones estándar de la impresora. Los soportes son requeridos.

Universidad del Valle de Guatemala | 2025

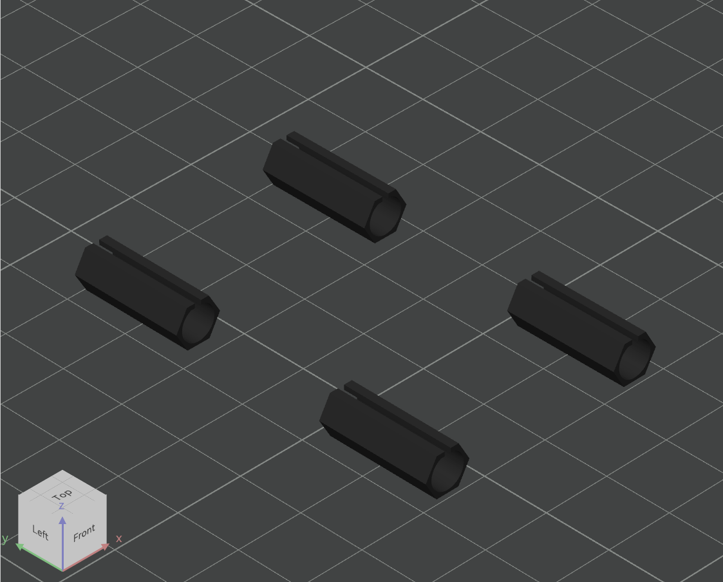
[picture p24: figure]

Ejes para los motores: En estas piezas se recomienda usar las configuraciones de definición más alta de la impresora. Esto significa tener la menor altura de capa posible. Estas piezas deben imprimirse sin soportes.

### 4.4. Manual de construcción

Para los pasos del ensamblaje, se encuentra adjunto el manual de construcción. Es importante que las conexiones se realicen entre el paso 11 y 12 del ensamblado.

Universidad del Valle de Guatemala | 2025

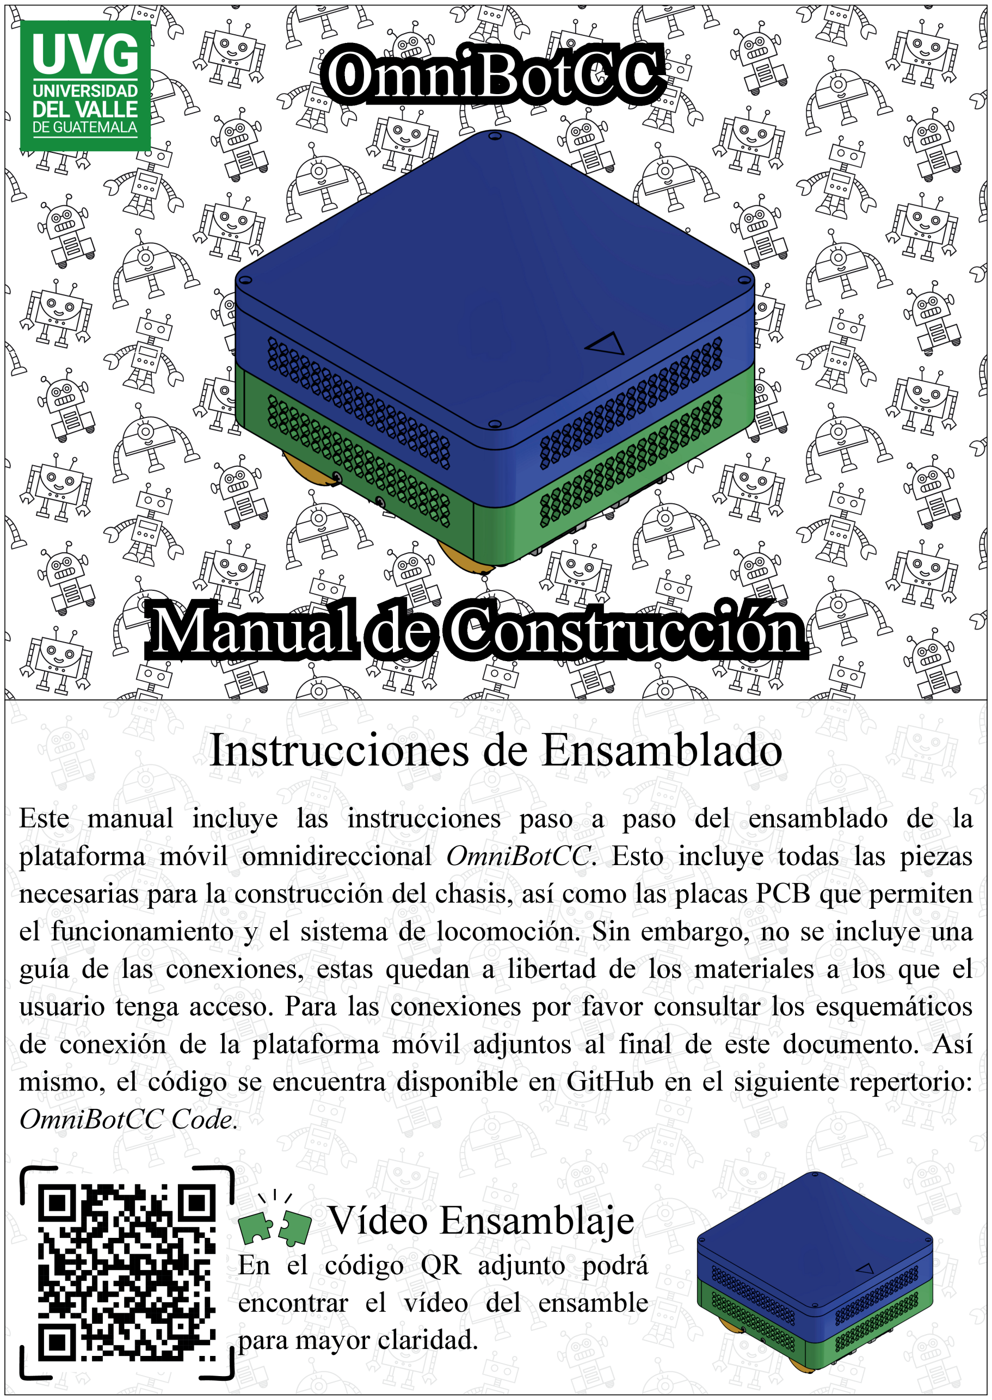
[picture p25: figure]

1) 2)

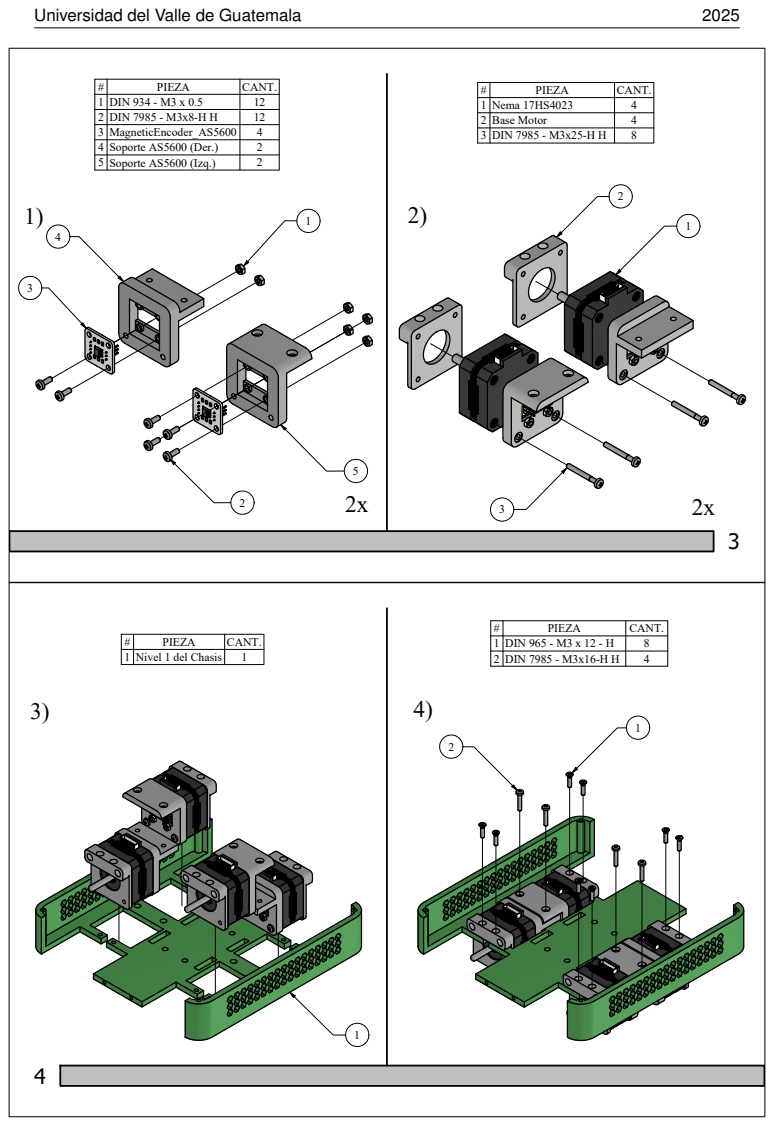
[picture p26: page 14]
PIEZA; CANT.; Soporte AS5600 (Izq.); Nema 17HS4023; Base Motor; DIN 7985 - M3x25-H H; Nivel 1 del Chasis; DIN 965 - M3 x 12 - H; DIN 7985 - M3x16-H H; Universidad del Valle de Guatemala

1 | DIN 934 - M3 x 0.5 | 12
2 | DIN 7985 - M3x8-H H | 12
3 | MagneticEncoder_AS5600 | 4
4 | Soporte AS5600 (Der.) | 2

5) 6)

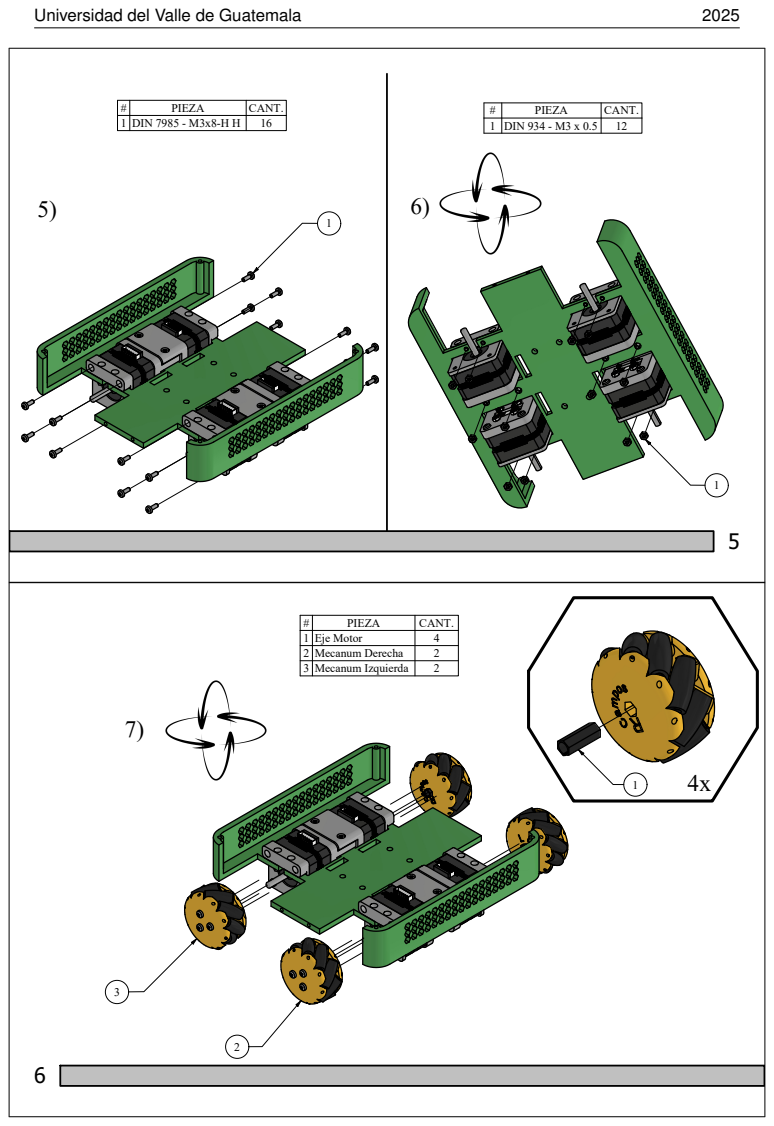
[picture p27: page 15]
PIEZA; CANT.; DIN 7985 - M3x8-H H; DIN 934 - M3 x 0.5; 1 Eje Motor; 2 Mecanum Derecha; 3 Mecanum Izquierda; Universidad del Valle de Guatemala

8 | 2 )

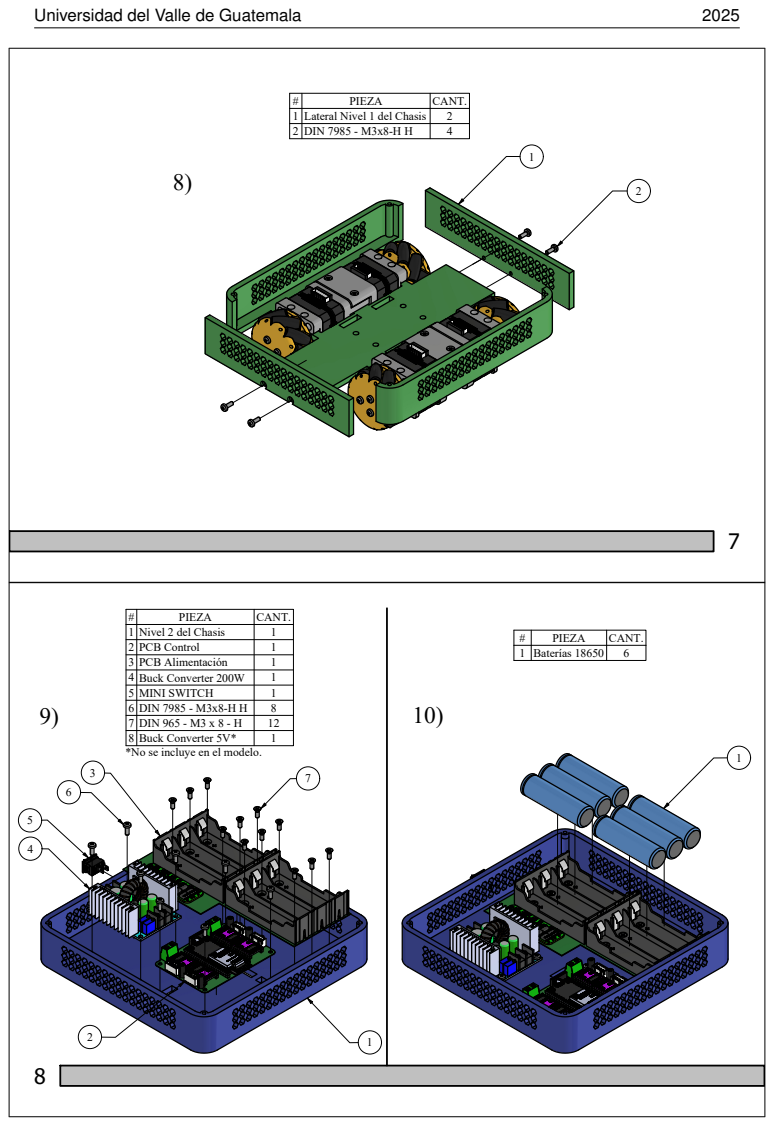
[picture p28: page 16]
PIEZA; CANT.; Lateral Nivel 1 del Chasis; DIN 7985 - M3x8-H H; 1 Nivel 2 del Chasis; 2 PCB Control; 3 PCB Alimentación; 4 Buck Converter 200W; 5 MINI SWITCH; 6 DIN 7985 - M3x8-H H; 7 DIN 965 - M3 x 8 - H; 8 Buck Converter 5V*; 1 Baterías 18650; Universidad del Valle de Guatemala

*No se incluye en el modelo.

11) 12)

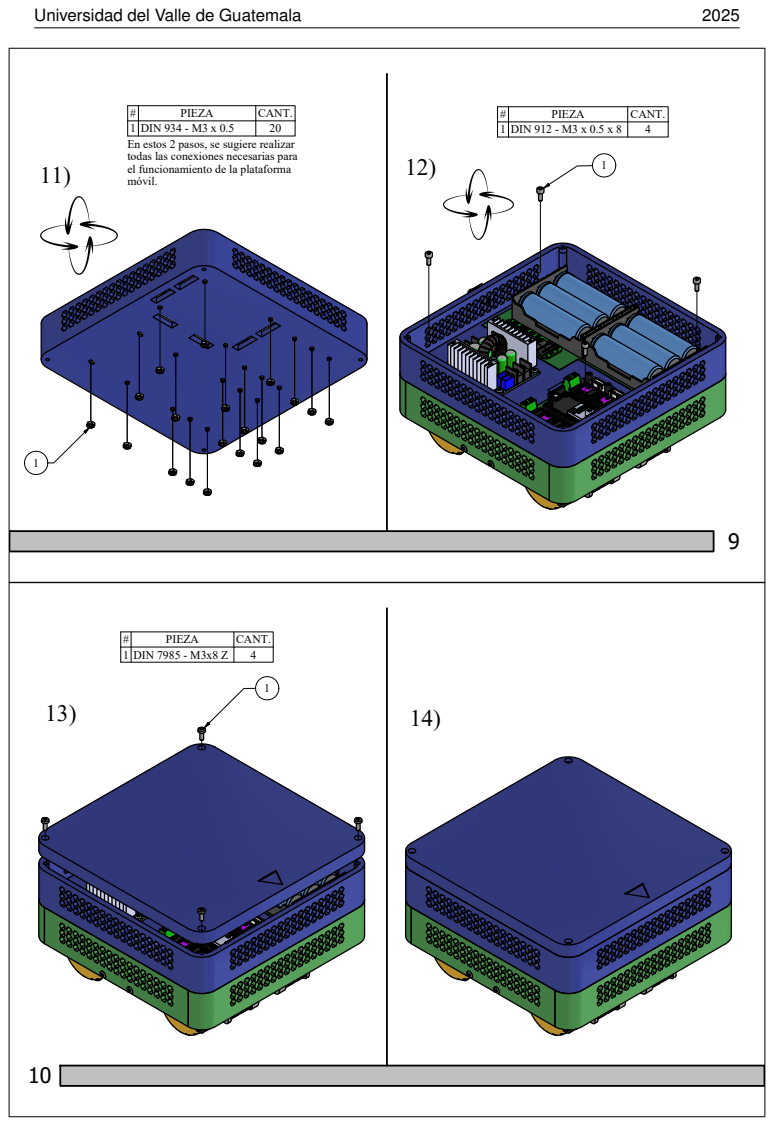
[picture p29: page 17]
PIEZA; CANT.; 1 DIN 934 - M3 x 0.5; 1 DIN 912 - M3 x 0.5 x 8; 1 DIN 7985 - M3x8 Z; Universidad del Valle de Guatemala

En estos 2 pasos, se sugiere realizar
todas las conexiones necesarias para
el funcionamiento de la plataforma
móvil.

Universidad del Valle de Guatemala | 2025

### 4.5. Esquemáticos y conexiones

### 4.5.1. Sistema de alimentación

El esquemático del circuito y la placa de alimentación del OmniBotCC son los siguientes:

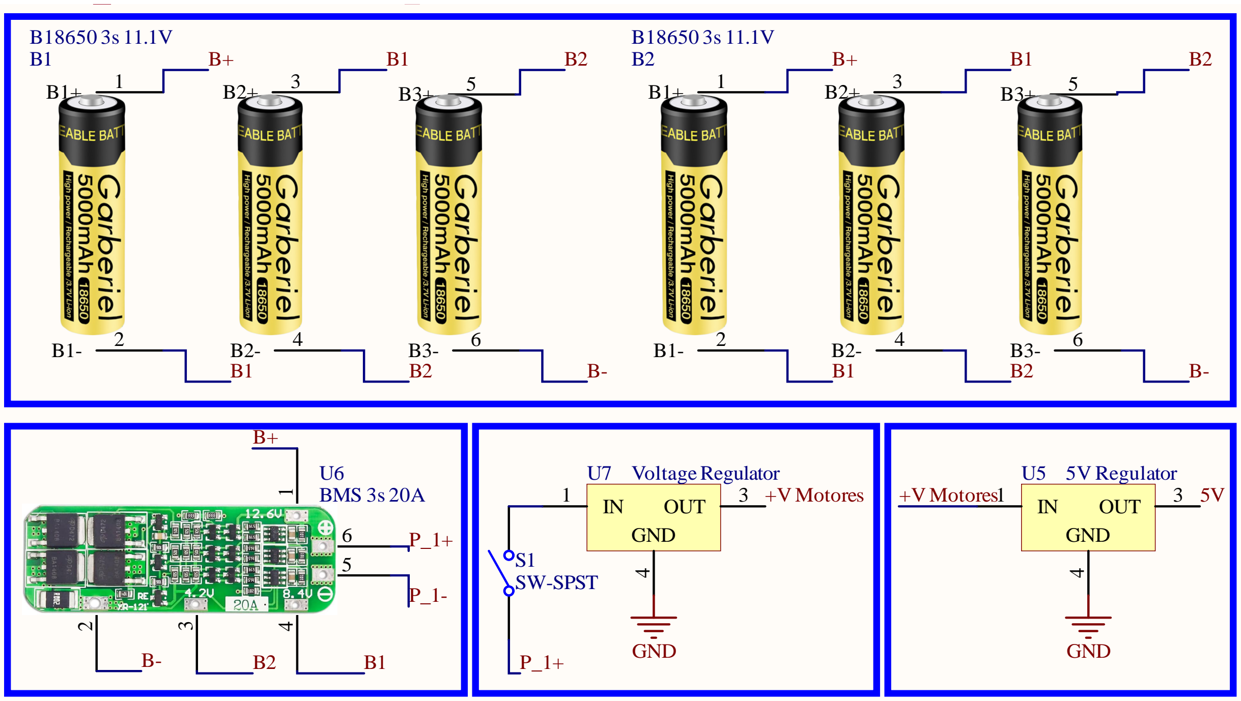
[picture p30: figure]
BMS 3s 20A; OUT; 4 GND; U7 Voltage Regulator; GND; +V Motores; S1 SW-SPST; U5 5V Regulator
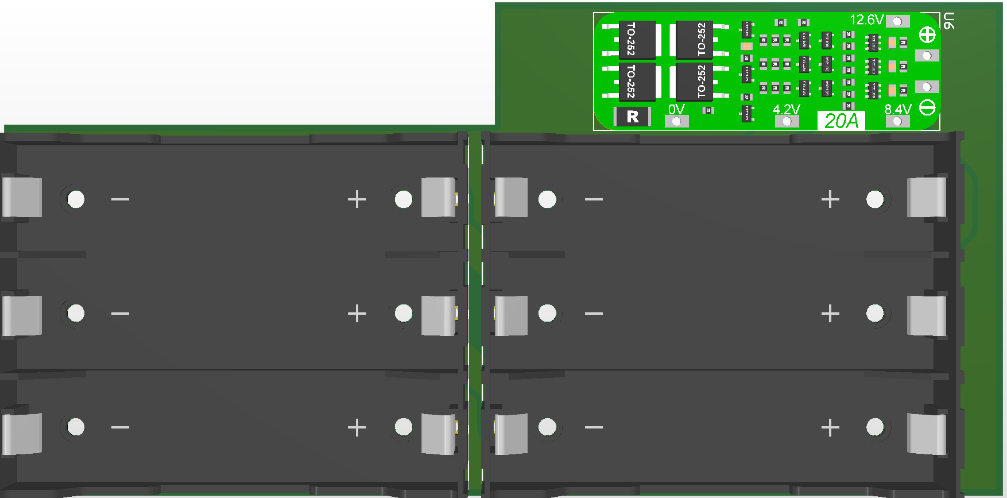
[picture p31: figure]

Es importante que al cargar las baterías, se haga siempre mediante el BMS, a 12.6V@2.6A durante 3 horas para una carga normal. Si se deseará una carga rápida la corriente puede subir hasta 5.2A durante 2 horas y media, sin embargo no es recomendable pues podría desgastar rápidamente las baterías.

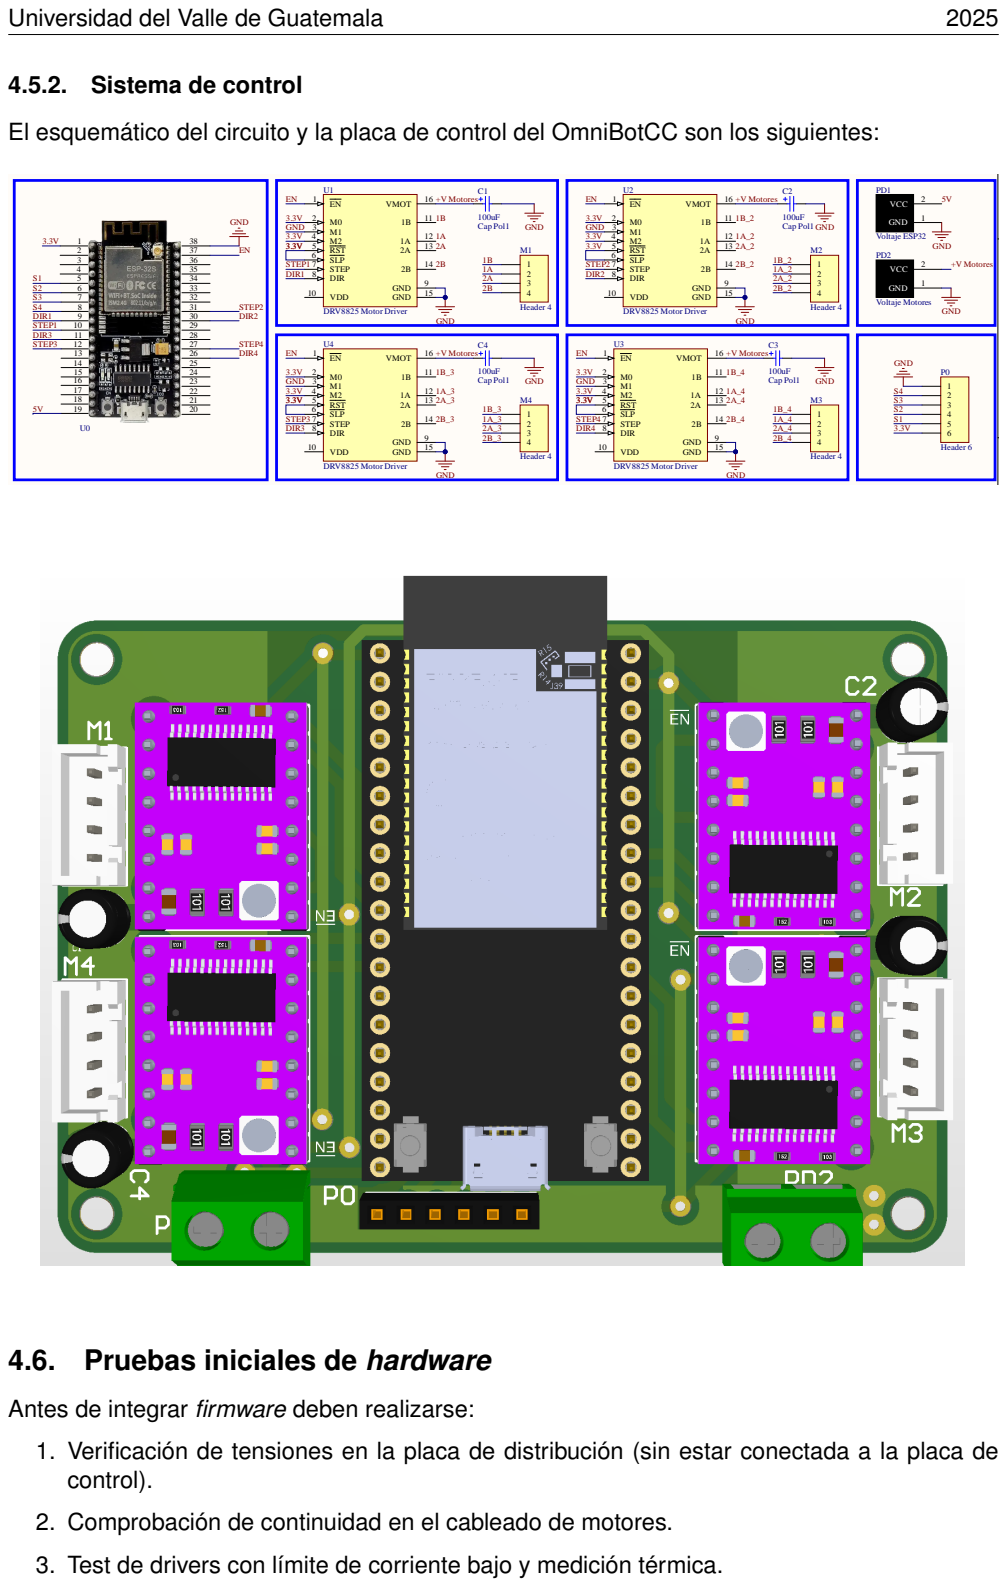
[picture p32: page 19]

El esquemático del circuito y la placa de control del OmniBotCC son los siguientes:

4.6. Pruebas iniciales de hardware

Antes de integrar firmware deben realizarse:

1. Verificación de tensiones en la placa de distribución (sin estar conectada a la placa de
control).

2. Comprobación de continuidad en el cableado de motores.

3. Test de drivers con límite de corriente bajo y medición térmica.

Universidad del Valle de Guatemala | 2025

## 5. Software/Firmware

La plataforma móvil está diseñada para poder programarse siempre fuera del ensamblaje. Por lo mismo, el código puede ser cualquiera, sin embargo a continuación se presenta un código que cumple con el funcionamiento básico de la plataforma móvil. Esto a través de comunicación Wi-Fi con un protocolo UDP y del control en lazo cerrado de los motores paso a paso.

### 5.1. Instalación del software/firmware

Para la instalación del firmware designado para el OmniBotCC debe compilarse y depurarse el código disponible en la siguiente carpeta de GitHub (https://github.com/Zent2/OmniBotCC/tree/main/ESP32/OmniBot_CC) para el ESP32 a través del entorno ESP-IDF. Sin embargo, antes de esto debe confirmarse que el nombre y contraseña de la red sea el correcto. Por la naturaleza de la plataforma móvil, cuenta con el nombre y contraseña del Wi-Fi del laboratorio del Robotat de la UVG. Si tiene alguna duda con respecto al código, se le recomienda leer los comentarios que el mismo contiene. Así mismo, se sugiere la lectura de la guía de programación de ESP-IDF (https://docs.espressif.com/projects/esp-idf/en/stable/esp32/get-started/index.html) para comprender el uso de las librerías usadas en la programación del OmniBotCC.

### 5.2. Protocolo de comunicación

El protocolo de comunicación que usa el OmniBotCC es UDP (User Datagram Protocol). Es un protocolo de comunicación inalámbrica enfocado en la velocidad, que sacrifica la garantía de envío y recibimiento de datos por la velocidad. Por la importancia de poder realizar el control de los motores en lazo cerrado, al mismo tiempo que se reciben los comandos de control, este protocolo fue el escogido para el OmniBotCC.

### 5.3. API/Comandos

Los comandos que debe recibir el ESP32 para funcionar son los siguientes:

Comando | Descripción
start/stop | Arrancan o detienen los cuatro motores simultáneamente.
mX_rpm= RPMS | Fija la velocidad del motor X en RPM. Sólo establece la magnitud (la di-rección se define por separado).
mX_dir= CW/CCW | Define la dirección de giro del motor X (CW = Clockwise, CCW = Counter-Clockwise).
mX_start / mX_stop | Arrancan o detienen de forma individual el motor X.

Para una mayor facilidad del control se recomienda usar las funciones de Matlab/Python disponibles en la siguiente carpeta de GitHub. (https://github.com/Zent2/OmniBotCC) Las funciones que se encuentran disponibles en esta carpeta son las siguientes:

Función | Descripción / Notas
robot_connect() | Configura el puerto/endpoint UDP para comunicarse con el ESP32. (Wi-Fi del Robotat)
robot_start() / robot_stop() | Inician o detienen el robot usando los últimos valores re-cibidos.
robot_set_velocities() | Envía un vector con las RPM de las cuatro ruedas (deter-minantes de ωbz, vbx, vby).

Universidad del Valle de Guatemala | 2025

### 5.4. Inicio Rápido

Para un inicio rápido y comprobación del correcto funcionamiento del OmniBotCC, puede correrse el programa llamado Inicio_Rapido.m. (https://github.com/Zent2/OmniBotCC/blob/main/Funciones_Matlab/Inicio_Rapido.m) En este podrá seguir un paso a paso para visualizar el funcionamiento de la plataforma móvil. Este control se realiza en lazo abierto, por lo que los movimientos no serán precisos.

1 | % -----------------------------------------------------------------------------
2 | % Inicio Rapido del OmniBotCC
3 | % -----------------------------------------------------------------------------
4 | % Proposito
5 | % | % Mostrar al usuario los comandos basicos del OmniRobotCC . Incluye :
6 | % | % - Demostracion de conexion y desconexion al Robot .
7 | % | % - Demostracion de inicio , parada y seteo de velocidades .
8 | %
9 | % Uso rapido
10 | % | 1) Ejecucion del script seccion por seccion ( antes de la ultima seccion )
| | para visualizar
11 | % | el correcto funcionamiento de los comandos .
12 | % | 2) Ejecucion de la ultima seccion para visualizar un movimiento simple
13 | % | sin retroalimentacion .
14 | %
15 | % Variables importantes ( entrada / salida )
16 | % | Entradas configurables :
17 | % | - Vel ( rpms )
18 | %
19 | % Comportamiento y supuestos
20 | % | - El Robot deberia tener suficiente espacio para moverse durante 2
21 | % | segundos hacia adelante e intentar regresar a su punto de inicio . Al no
22 | % | tener retroalimentacion no se asegura que esto sea cierto .
23 | % | - El codigo no es de control , solo de demostracion .
24 | %
25 | % Tips rapidos de uso / debugging
26 | % | - Verifique que el Robot tenga espacio a sus alrededores .
27 | % | - Verifique que el Robot este conectado al Wi -Fi del Robotat , esto lo
28 | % | indica la LED Azul del ESP32 .
29 | % | - Si el ESP32 no conecta , reinicie el ESP32 y compruebe el estado del
30 | % | Wi -Fi del Robotat .
31 | %
32 | % Autores / version
33 | % | - Autor : Christian Campos
34 | % | - Version : 1.0
35 | % | - Fecha : 2025 -10 -13
36 | % -----------------------------------------------------------------------------

37
38 | %% Comando para conexion con el Robot
39 | robot_connect () ;

40
41 | %% Comando para enviar velocidades al Robot ( aun no esta en movimiento )
42 | rpm_vector = -10*[0 0 0 1];
43 | robot_set_velocities ( rpm_vector ) ;

44
45 | %% Comando para comenzar el movimiento del Robot con las velocidades guardadas
46 | robot_start () ;

47
48 | %% Comando para enviar velocidades al Robot ( modifica las velocidades actuales )
49 | rpm_vector = -10*[ -1 1 1 -1];
50 | robot_set_velocities ( rpm_vector ) ;

51
52 | %% Comando para detener el Robot ( los motores siguen encendidos )
53 | rpm_vector = [0 0 0 0];
54 | robot_set_velocities ( rpm_vector ) ;

55
56 | %% Comando para detener el Robot y apagar los motores .
57 | robot_stop () ;

58

Universidad del Valle de Guatemala | 2025
59 | %% Comando para desconexion con el Robot
60 | robot_disconnect () ;

61
62 %% Demostracion movimiento sencillo sin retroalimentacion .

63
64 robot_connect () ;

65
66 | % Velocidad base en rpm (se puede ajustar hasta a 400 rpms )
67 | vel = 40;

68
69 | % Definicion de los vectores de velocidad de cada rueda
70 | % Orden : [m1 m2 m3 m4]
71 | movimientos = {
72 | 'Adelante ', | vel * [ | 1 | 1 | 1 | 1 ]; | % +Y ( avanza hacia adelante )
73 | 'Atras ', | vel * [ -1 | -1 | -1 | -1 ]; | % -Y ( retrocede )
74 | 'Derecha ', | vel * [ | 1 | -1 | -1 | 1 ]; | % +X ( desplaza a la derecha )
75 | 'Izquierda ', | vel * [ -1 | 1 | 1 | -1 ]; | % -X ( desplaza a la izquierda )
76 | 'Giro CW ', | vel * [ | 1 | -1 | 1 | -1 ]; | % Rotacion horario
77 | 'Giro CCW ', | vel * [ -1 | 1 | -1 | 1 ]; | % Rotacion antihorario
78 | };
79 | pause (1) ;

80
81 | % Velocidades 0 antes de iniciar
82 | robot_set_velocities ([0 0 0 0]) ;

83
84 | % Iniciar robot con velocidades 0
85 | robot_start () ;

86
87 | % Vamos a realizar todos los movimientos
88 | for k = 1: size ( movimientos ,1)
89 | nombre = movimientos {k ,1};
90 | rpm_vector = movimientos {k ,2};

91
92 disp ([ 'Movimiento : ', nombre ]) ;

93
94 | % Asignar velocidades
95 | robot_set_velocities ( rpm_vector ) ;
96 | tic;
97 | while toc < 2
98 | % loop de espera de 2 segundos
99 | end
100 | % Detener Robot ( sin apagar motores )
101 | robot_set_velocities ([0 0 0 0]) ;
102 | pause (1) ; % pequena pausa entre movimientos
103 | end

104
105 | % Detener Robot
106 | robot_stop () ;

107
108 disp ('Rutina completa .');

109
110 | % Desconectar Robot
111 | robot_disconnect () ;

112
113 | %% Demostracion con velocidades X y Y
114 | % Parametros fisicos del robot
115 | w = ((46.8+82.3) /2) /1000; | % m
116 | l = ((74.65+32.35) /2) /1000; % m
117 | r = 48/1000; | % radio rueda [m]
118 | % Limites motores
119 | rpm_max = 80; | % rpm

120
121 | H0 = [ -l - w , 1, -1;
122 | l + w , 1, | 1;
123 | l + w , 1, -1;
124 | -l - w , 1, | 1 ];

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

Universidad del Valle de Guatemala | 2025

## 6. Calibración y mantenimiento

### 6.1. Calibración AS5600

Nombre | Dirección | Tipo (R/W) | Bits | Descripción
ZMCO | 0x00 | R | 1:0 | Número de veces que se ha realizado BURN_ANGLE (máx. 3)
ZPOS | 0x01-0x02 | R/W | 11:0 | Posición cero configu-rada (offset del ángulo)
MANG | 0x05-0x06 | R/W | 11:0 | Rango máximo del án-gulo de medición
CONF | 0x07-0x08 | R/W/P | WD (bit 7) | Activación del Watch-dog
| | | FTH (6:4) | Límite del filtro rápido
| | | SF (3:2) | Filtro lento
| | | PWMF (1:0) | Frecuencia PWM
| | | OUTS (3:2) | Configuración de la sa-lida
| | | HYST (1:0) | Histéresis
| | | PM (1:0) | Modo de alimentación
STATUS | 0x0B | R | MD (bit 5) | Imán detectado
| | | ML (bit 4) | Imán muy lejos
| | | MH (bit 3) | Imán muy cerca
RAW_ANGLE | 0x0C-0x0D | R | 11:0 | Ángulo sin procesar (valor bruto)
ANGLE | 0x0E-0x0F | R | 11:0 | Ángulo corregido según posición cero
BURN | 0xFF | W | 7:0 | Registro especial para grabar configuración en memoria OTP

El cuadro muestra los registros y direcciones para comunicación I2C del AS5600. Para grabar la configuración de posición (ZPOS y MPOS) en la memoria, debe enviarse el valor 0x80 al registro BURN (comando BURN_Angle). Esto solo puede realizarse hasta tres veces, lo cual se refleja en el valor del registro ZMCO. Para grabar los ajustes de configuración (CONF y otros), se debe enviar 0x40 al mismo registro (BURN_Setting); esta operación solo puede hacerse una vez y únicamente si no se ha realizado ningún BURN_ANGLE previamente. Durante todo este proceso es necesario que el pin GPO este conectado a GND (tierra). Así mismo, este proceso puede realizarse usando el código: AS5600_Configuration.c. (https://github.com/Zent2/OmniBotCC/blob/main/ESP32/OmniBot_CC/main/AS5600_Configuration.c)

Sin embargo, hay versiones del AS5600 que para permitir la lectura analógica solo es necesario colocar el mismo voltaje de alimentación en el pin GPO.

### 6.2. Calibración OmniBotCC

Si se usa el sistema OptiTrack que se encuentra en el ecosistema Robotat, debe especificarse un cuerpo rígido dentro del sistema de Motion. En ese caso, para obtener correctamente la posición y orientación de la plataforma dentro del Robotat, se deben seguir los siguientes pasos de calibración:

Universidad del Valle de Guatemala | 2025
1. Colocar la plataforma en el centro del área de captura del Robotat, con la dirección positiva del eje X tanto de la plataforma como del Robotat alineadas.
2. Visualizar la posición actual de los marcadores en la interfaz del sistema.
3. Leer los valores de posición y orientación desde MATLAB o Python; estos valores serán las compensaciones para determinar con precisión el centro de la plataforma.

Cabe aclarar, que el OmniBotCC solo puede variar su ángulo ψ (yaw) y su posición en el plano XY. Por lo mismo, solo estos datos son requeridos para usarse posteriormente como offsets dentro del control. Para este proceso puede usarse el scrypt Calibracion_Robot.m (https://github.com/Zent2/OmniBotCC/blob/main/Funciones_Matlab/Calibracion_Robot.m)

### 6.3. Mantenimiento OmniBotCC

El OmniBot CC es una plataforma móvil que hasta la fecha es muy reciente. Por lo que los intervalos necesarios mantenimiento se desconocen con certeza. Sin embargo, en base a los componentes con los que cuenta, algunos intervalos recomendados, considerando un uso continuo, son los siguientes:

Cada 2 semanas: Revisar apriete de tornillos, estado de ejes y acoplamientos. Como se pudo visualizar en la Sección 4.3, los acoplamientos entre los ejes y las ruedas son bastante delgados. Esto los vuelve muy vulnerables al desgaste, en especial si se usan velocidades muy altas.

Cada mes: Revisar desgaste de ruedas; reemplazar si hay deterioro. Esto debido a que las ruedas mecanum requieren que sus rodillos tengan suficiente fricción con el suelo para lograr un movimiento omnidireccional.

Cada 3 meses: Comprobar salud del pack de baterías y balanceo; reemplazar celdas defectuosas. Esto debe hacerse con extrema precaución, pues como se indicó anteriormente, las celdas 18650 son peligrosas. Asegúrese de no realizar corto-circuito en ninguna de las celdas, de no tener ningún circuito conectado al momento de manipularlas y sobre todo al realizar un reemplazo, de colocar celdas con las mismas características que las originales o en su defecto, cambiar todas las celdas.

Cada actualización de firmware: Verificar parámetros de seguridad y restaurar límites si fue necesario. Esto incluye valores del control en lazo cerrado de los motores, como valores de velocidades máximas y mínimas de la plataforma móvil.

Se recomienda, como en todo sistema eléctrico o mecánico, llevar un registro de mantenimiento. Para el mismo, se encuentra el siguiente cuadro de ejemplo:

Fecha | Actividad | Observaciones

Universidad del Valle de Guatemala | 2025

## 7. Especificaciones técnicas

Dimensiones: 190 mm (largo) x 190 mm (ancho) x 90 mm (alto).

Masa: apróximadamente 3.2 kg (con baterías).

Tensión nominal: 12.6 V (pack 3s2p).

Corriente máxima continua: 20 A (limitado y controlado por el BMS).

Motores: NEMA17 de 23mm de grosor, torque nominal 0.45 Nm.

Velocidad máxima nominal de translación: 2.0 m/s (400 rpms)

Velocidad máxima nominal de rotación: 17.0 rad/s (400 rpms)

Sensores: 4 x AS5600 (resolución angular de 12 bits).

Comunicación: Wi-Fi (UDP), puerto por defecto 12345 e IP estática 192.168.50.222.

Controlador embebido: ESP32 (dual-core, 240 MHz) con FreeRTOS.

Universidad del Valle de Guatemala | 2025

## 8. Soporte y licencias

Si se necesita soporte:

Diseñador: Christian Alessandro Campos López — cam21760@uvg.edu.gt

Tutor académico: MSc. Miguel E. Zea A. — mezea@uvg.edu.gt

OmniBotCC - Manual de Construcción Versión 1.0 (2025)
© 2025 Universidad del Valle de Guatemala. Departamento de Ingeniería Electrónica, Mecatrónica y Biomédica. Este manual cubre el ensamblaje mecánico y las conexiones eléctricas básicas. Fabricado en Guatemala.
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

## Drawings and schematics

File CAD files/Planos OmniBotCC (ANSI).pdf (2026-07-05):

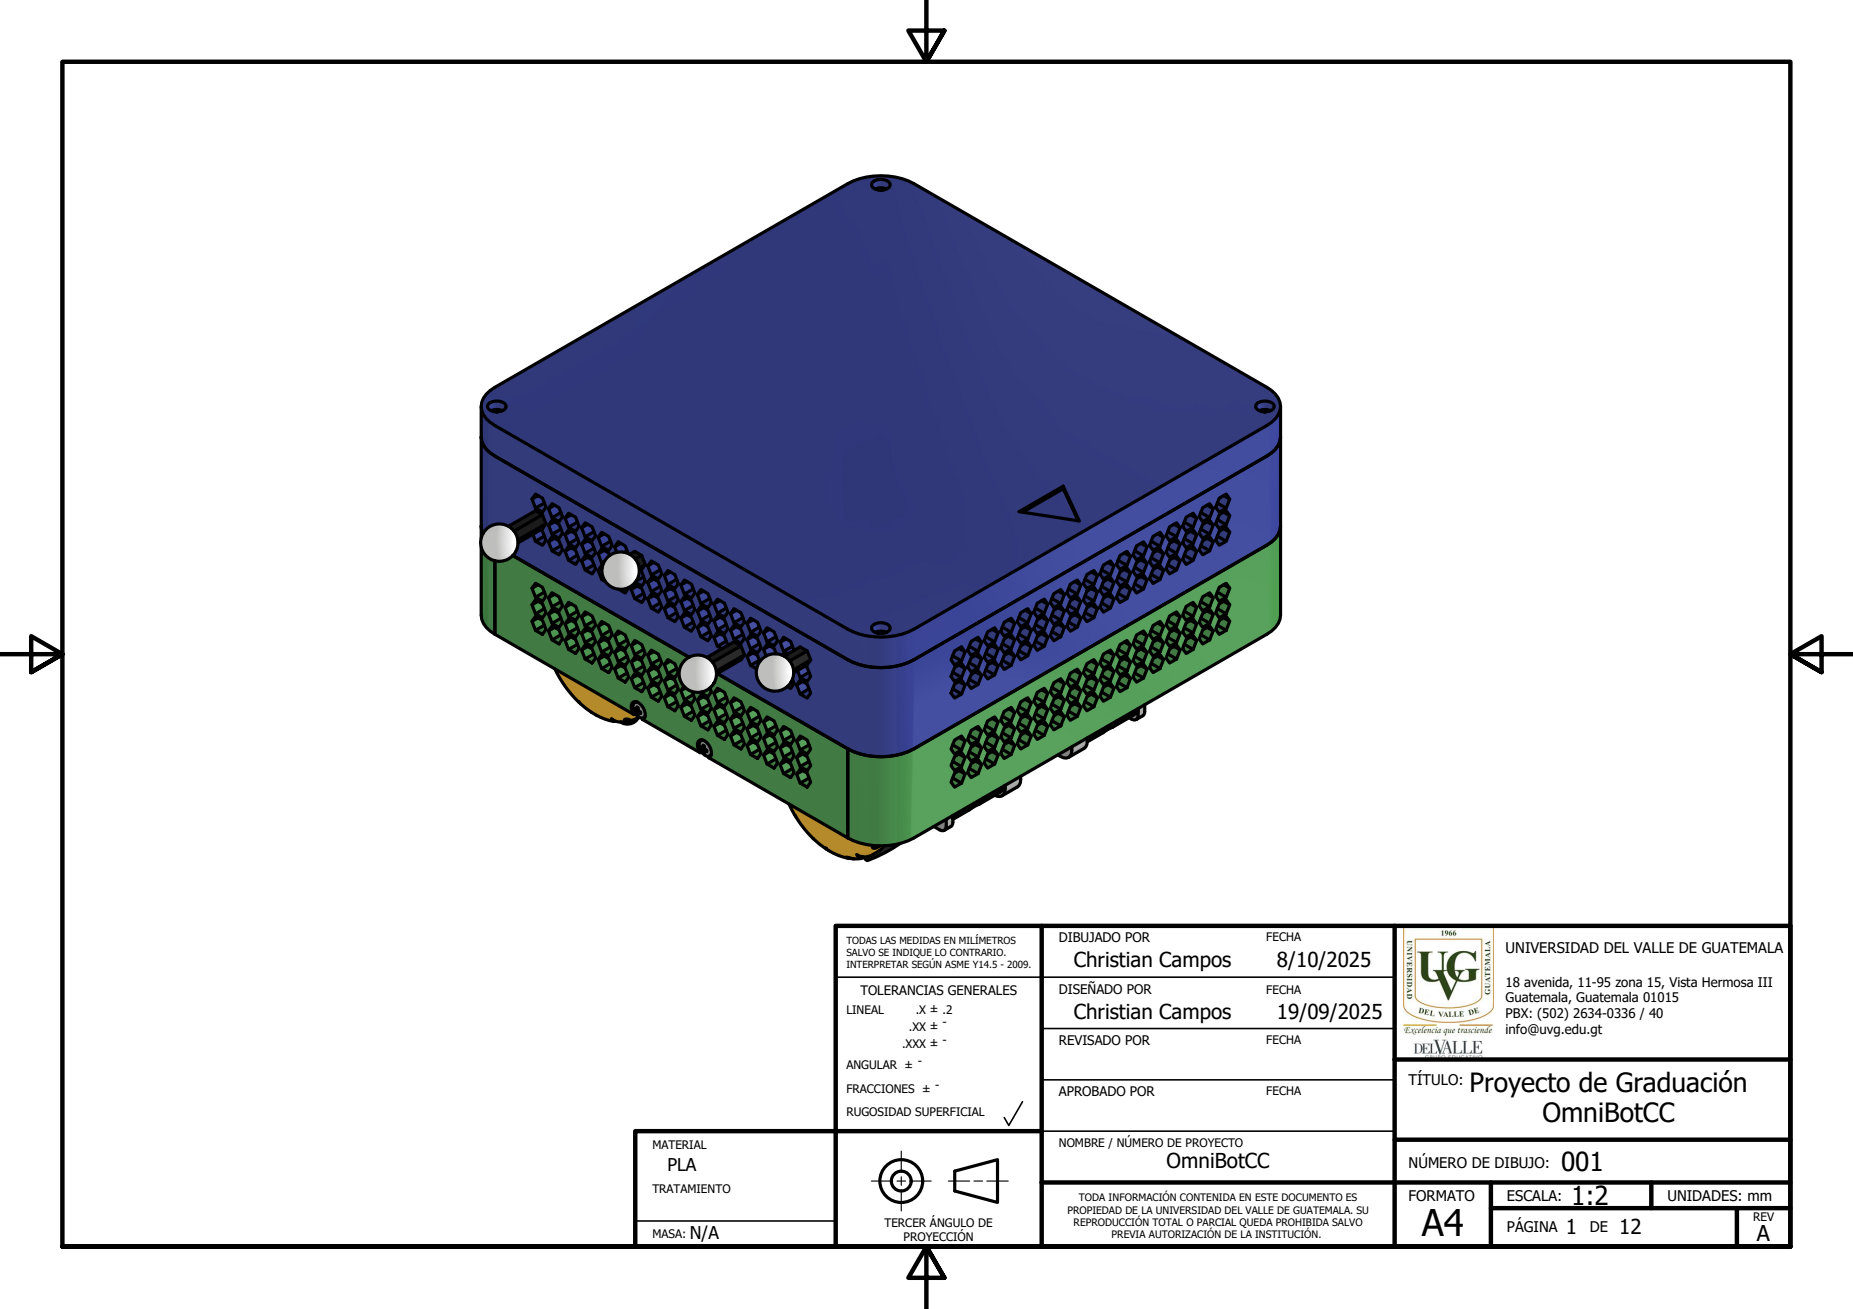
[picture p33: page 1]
APROBADO POR; REVISADO POR

TODAS LAS MEDIDAS EN MILÍMETROS SALVO SE INDIQUE LO CONTRARIO. INTERPRETAR SEGÚN ASME Y14.5 - 2009. | DIBUJADO POR FECHA Christian Campos 8/10/2025 | UNIVERSIDAD DEL VALLE DE GUATEMALA 18 avenida, 11-95 zona 15, Vista Hermosa III Guatemala, Guatemala 01015 PBX: (502) 2634-0336 / 40 info@uvg.edu.gt

TOLERANCIAS GENERALES LINEAL .X ± .2 -.XX ± .XXX ± --ANGULAR ± FRACCIONES ± -RUGOSIDAD SUPERFICIAL | DISEÑADO POR FECHA Christian Campos 19/09/2025

Proyecto de Graduación
OmniBotCC

NOMBRE / NÚMERO DE PROYECTO

NÚMERO DE DIBUJO:

TODA INFORMACIÓN CONTENIDA EN ESTE DOCUMENTO ES PROPIEDAD DE LA UNIVERSIDAD DEL VALLE DE GUATEMALA. SU PREVIA AUTORIZACIÓN DE LA INSTITUCIÓN. REPRODUCCIÓN TOTAL O PARCIAL QUEDA PROHIBIDA SALVO | FORMATO A4 | ESCALA: 1:2 | UNIDADES: mm

TERCER ÁNGULO DE
PROYECCIÓN

PÁGINA DE | REV A

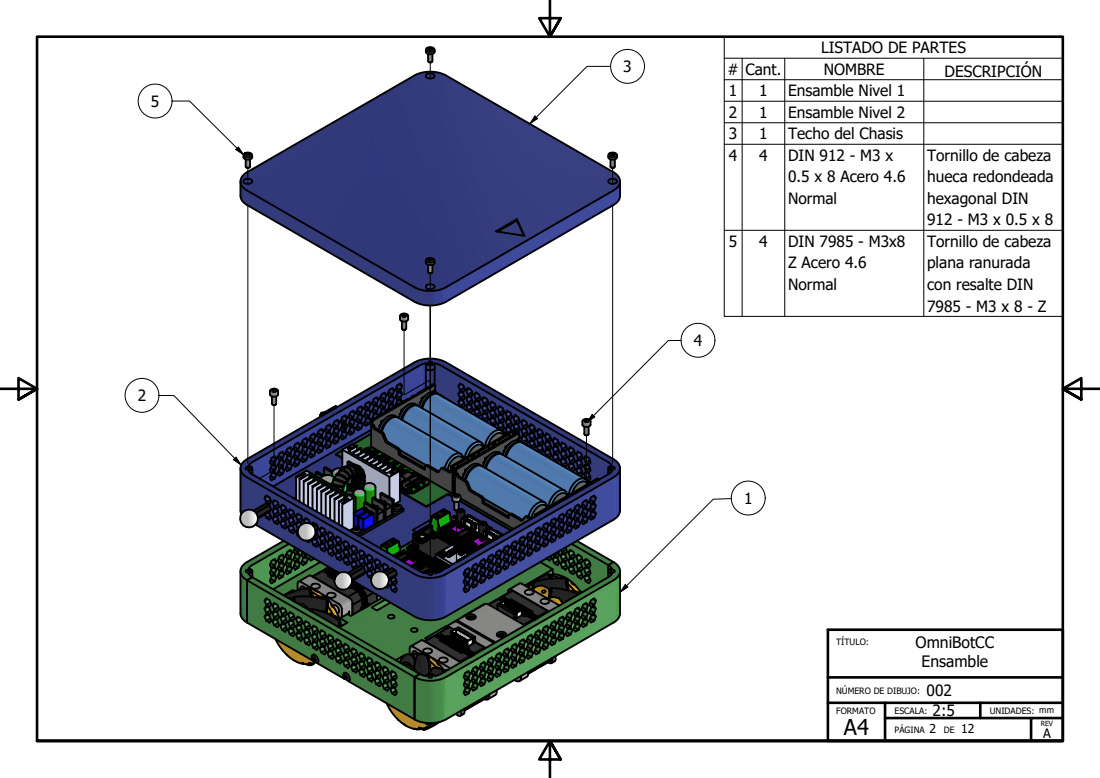
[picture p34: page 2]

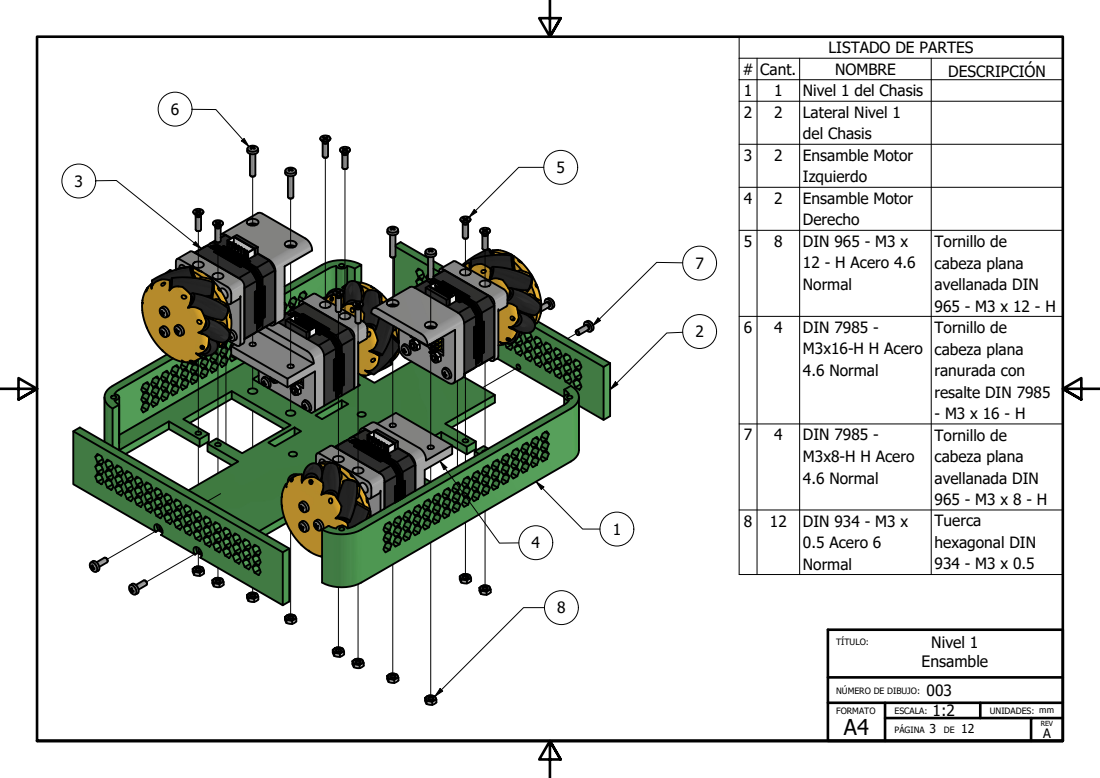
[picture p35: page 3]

# | C a n t . | N O M B R E | Ó D E S C R I P C I N
1 | 1 | N i v el 1 d el C h a s i s
2 | 2 | L a t e r al N i v el 1 d el C h a s i s

3 | 2 | E n s a m ble M o t o r I z q u i e r d o

4 | 2 | E n s a m ble M o t o r D e r e c h o

8 | D I N 9 al 5 6 5 -M 3 x 1 2 -H A c e r o 4 . 6 N o r m | T o r n illo d e c a b e z a pla n a a v ella n a d a D I N 9 6 5 -M 3 x 1 2 -H

4 | D I N 7 9 8 5 al 6 -M 3 x 1 6 -H H A c e r o 4 . 6 N o r m | T o r n illo d e c a b e z a pla n a r a n u r a d a c o n r e s alt e D I N 7 9 8 5 -M 3 x 1 6 -H

4 | D I N 7 9 8 5 al 7 -M 3 x 8 -H H A c e r o 4 . 6 N o r m | T o r n illo d e c a b e z a pla n a a v ella n a d a D I N 9 6 5 -M 3 x 8 -H

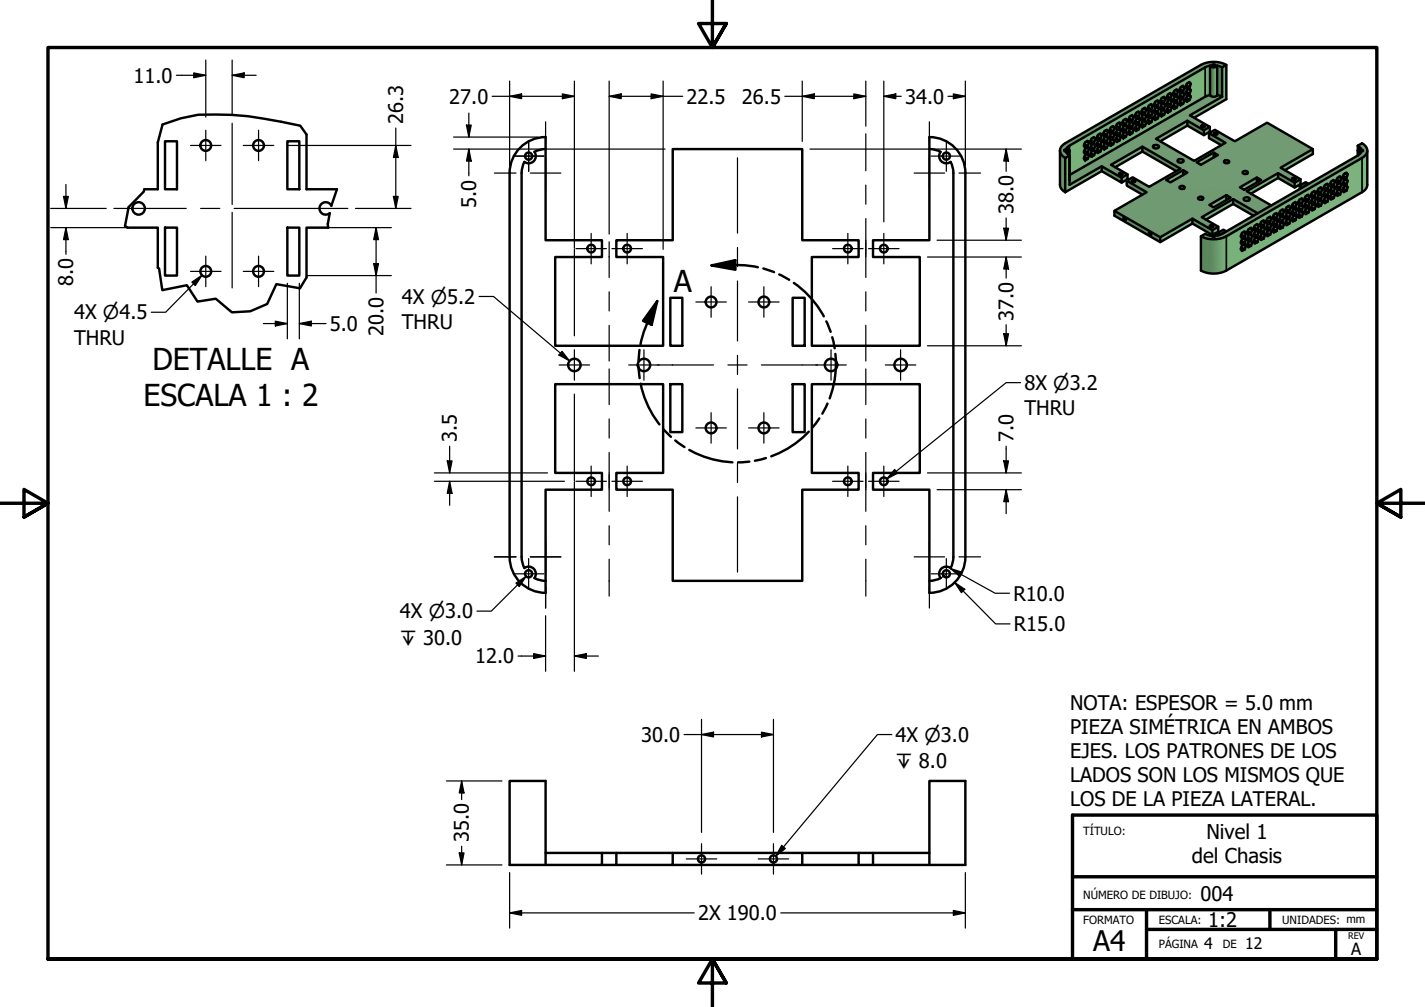
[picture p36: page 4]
DETALLE A ESCALA 1 : 2; TÍTULO:; Nivel 1; del Chasis

NOTA: ESPESOR = 5.0 mm
PIEZA SIMÉTRICA EN AMBOS
EJES. LOS PATRONES DE LOS
LADOS SON LOS MISMOS QUE
LOS DE LA PIEZA LATERAL.

NÚMERO DE DIBUJO:

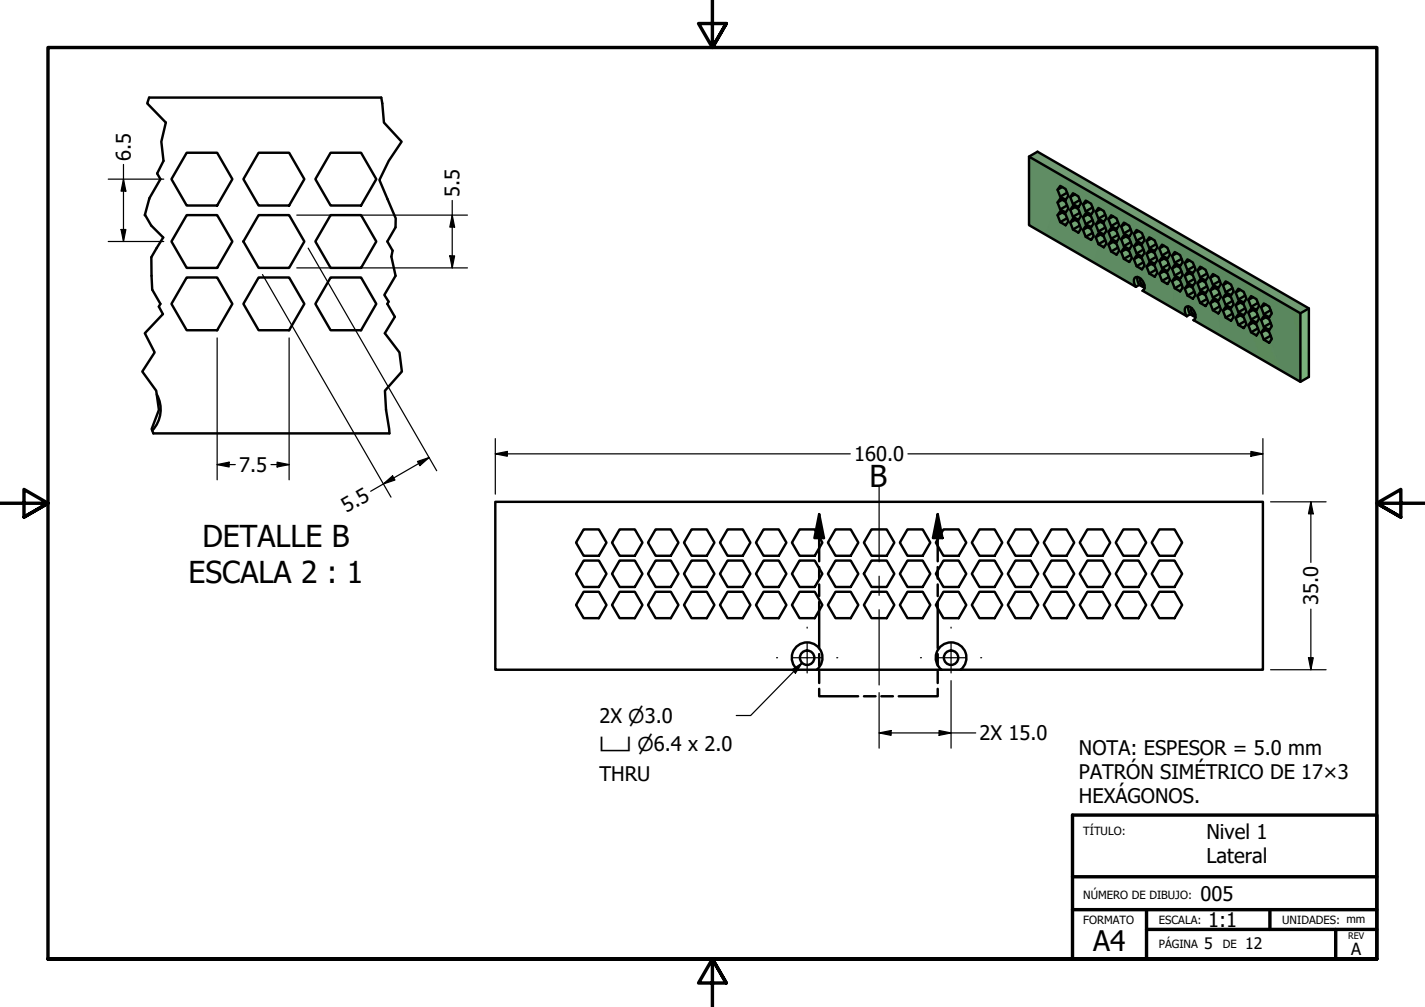
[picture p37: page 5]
DETALLE B ESCALA 2 : 1; TÍTULO:; Nivel 1

NOTA: ESPESOR = 5.0 mm
PATRÓN SIMÉTRICO DE 17×3
HEXÁGONOS.

NÚMERO DE DIBUJO:

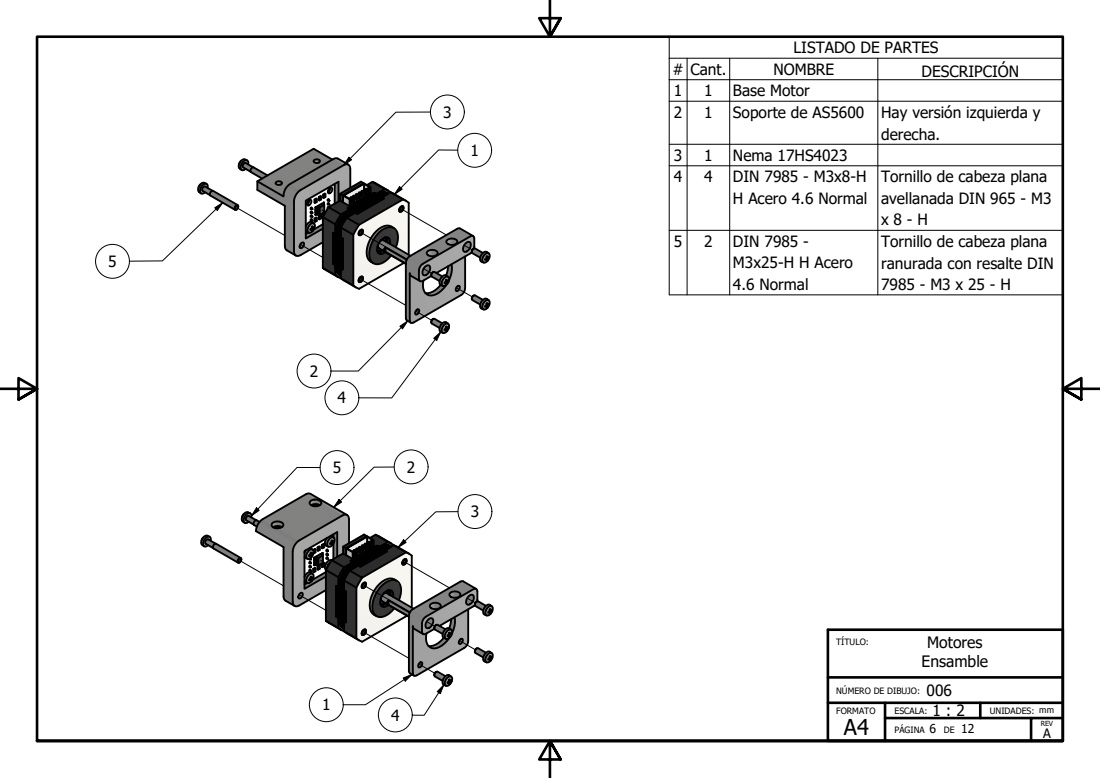
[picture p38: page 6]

LISTADO DE PARTES

# | Cant. | NOMBRE | DESCRIPCIÓN
1 | 1 | Base Motor
2 | 1 | Soporte de AS5600 | Hay versión izquierda y derecha.

3 | 1 | Nema 17HS4023
4 | 4 | DIN 7985 - M3x8-H H Acero 4.6 Normal | Tornillo de cabeza plana avellanada DIN 965 - M3 x 8 - H

5 | 2 | DIN 7985 -M3x25-H H Acero 4.6 Normal | Tornillo de cabeza plana ranurada con resalte DIN 7985 - M3 x 25 - H

NÚMERO DE DIBUJO:

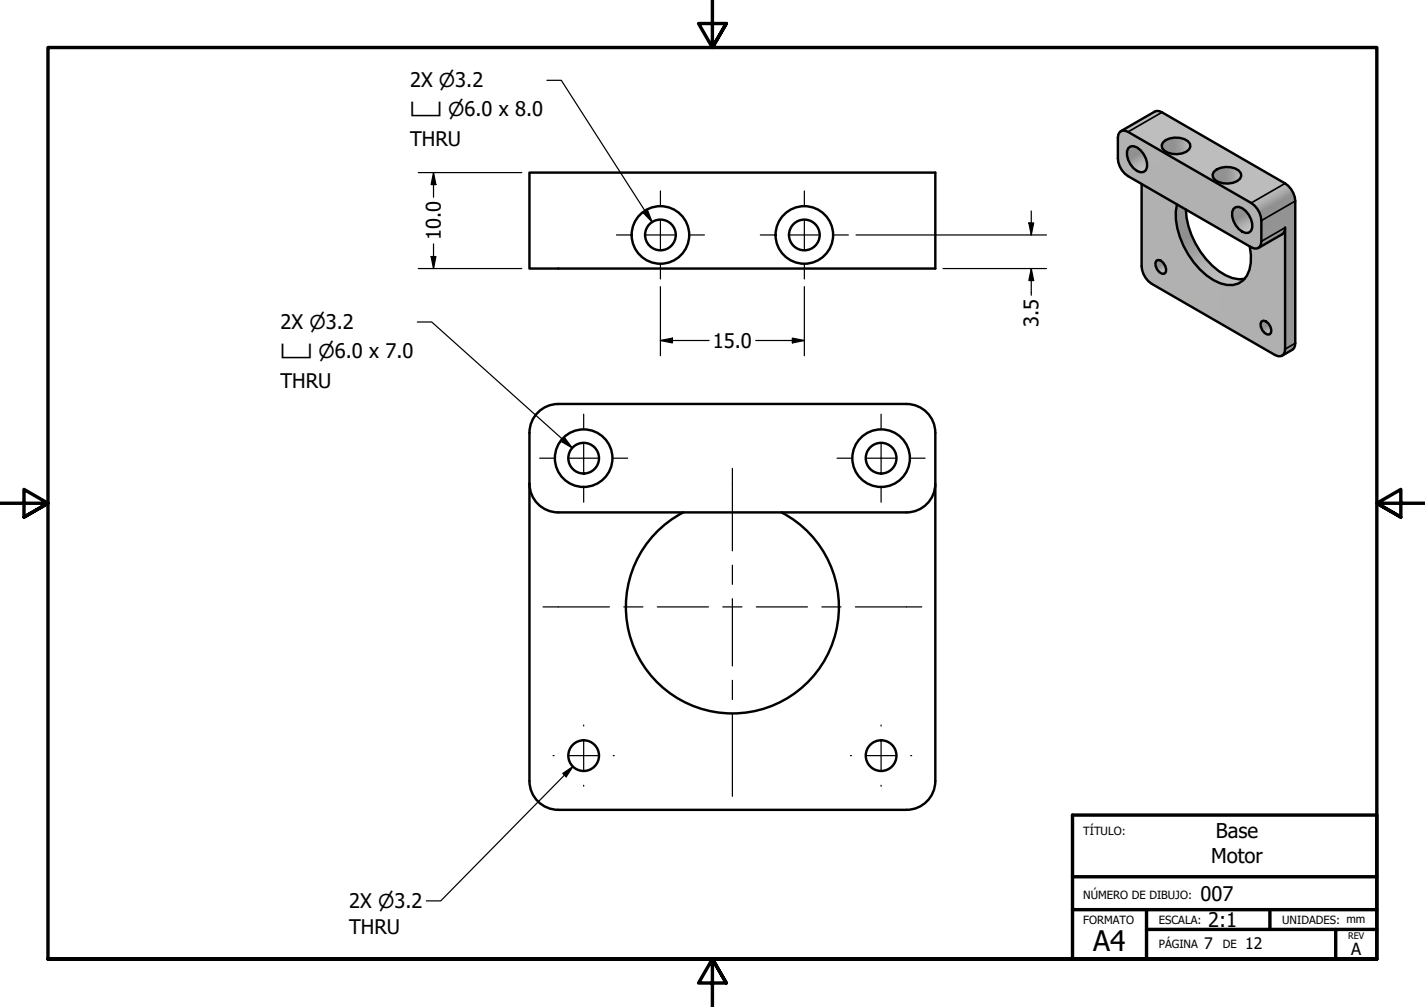
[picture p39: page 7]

NÚMERO DE DIBUJO:

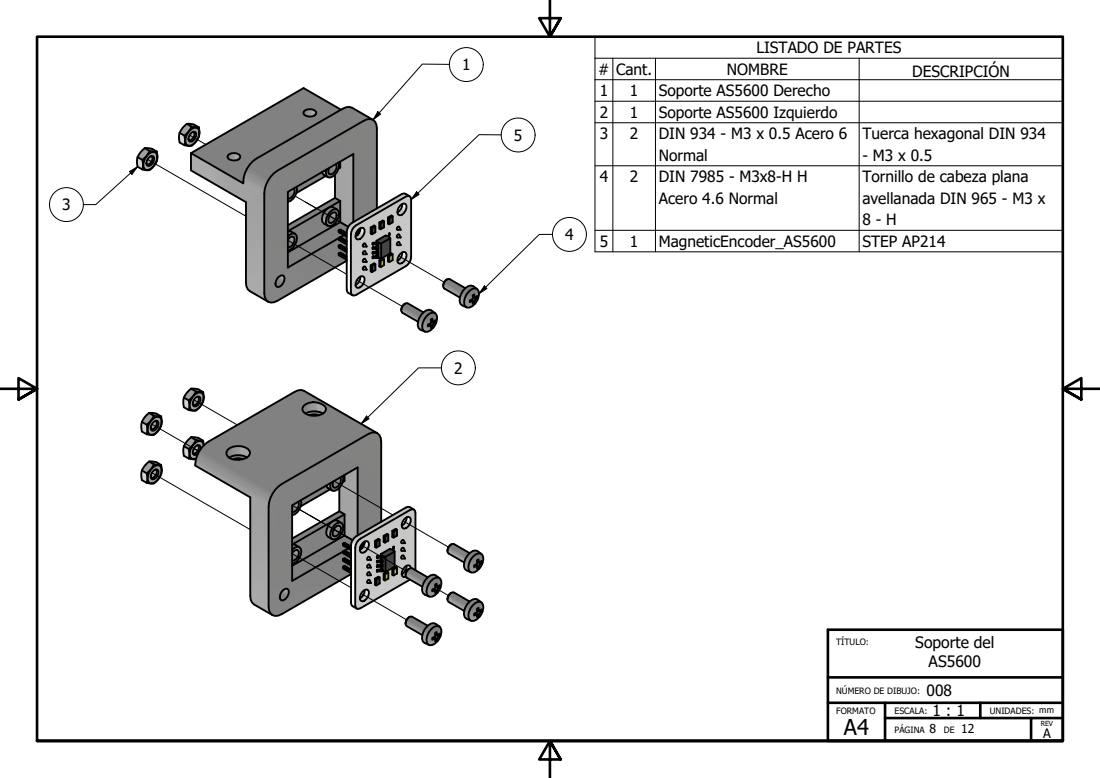
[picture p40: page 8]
TÍTULO:; Soporte del

LISTADO DE PARTES

# | Cant. | NOMBRE | DESCRIPCIÓN
1 | 1 | Soporte AS5600 Derecho
2 | 1 | Soporte AS5600 Izquierdo
3 | 2 | DIN 934 - M3 x 0.5 Acero 6 Normal | Tuerca hexagonal DIN 934 - M3 x 0.5

4 | 2 | DIN 7985 - M3x8-H H Acero 4.6 Normal | Tornillo de cabeza plana avellanada DIN 965 - M3 x 8 - H

5 | 1 | MagneticEncoder_AS5600 | STEP AP214

NÚMERO DE DIBUJO:

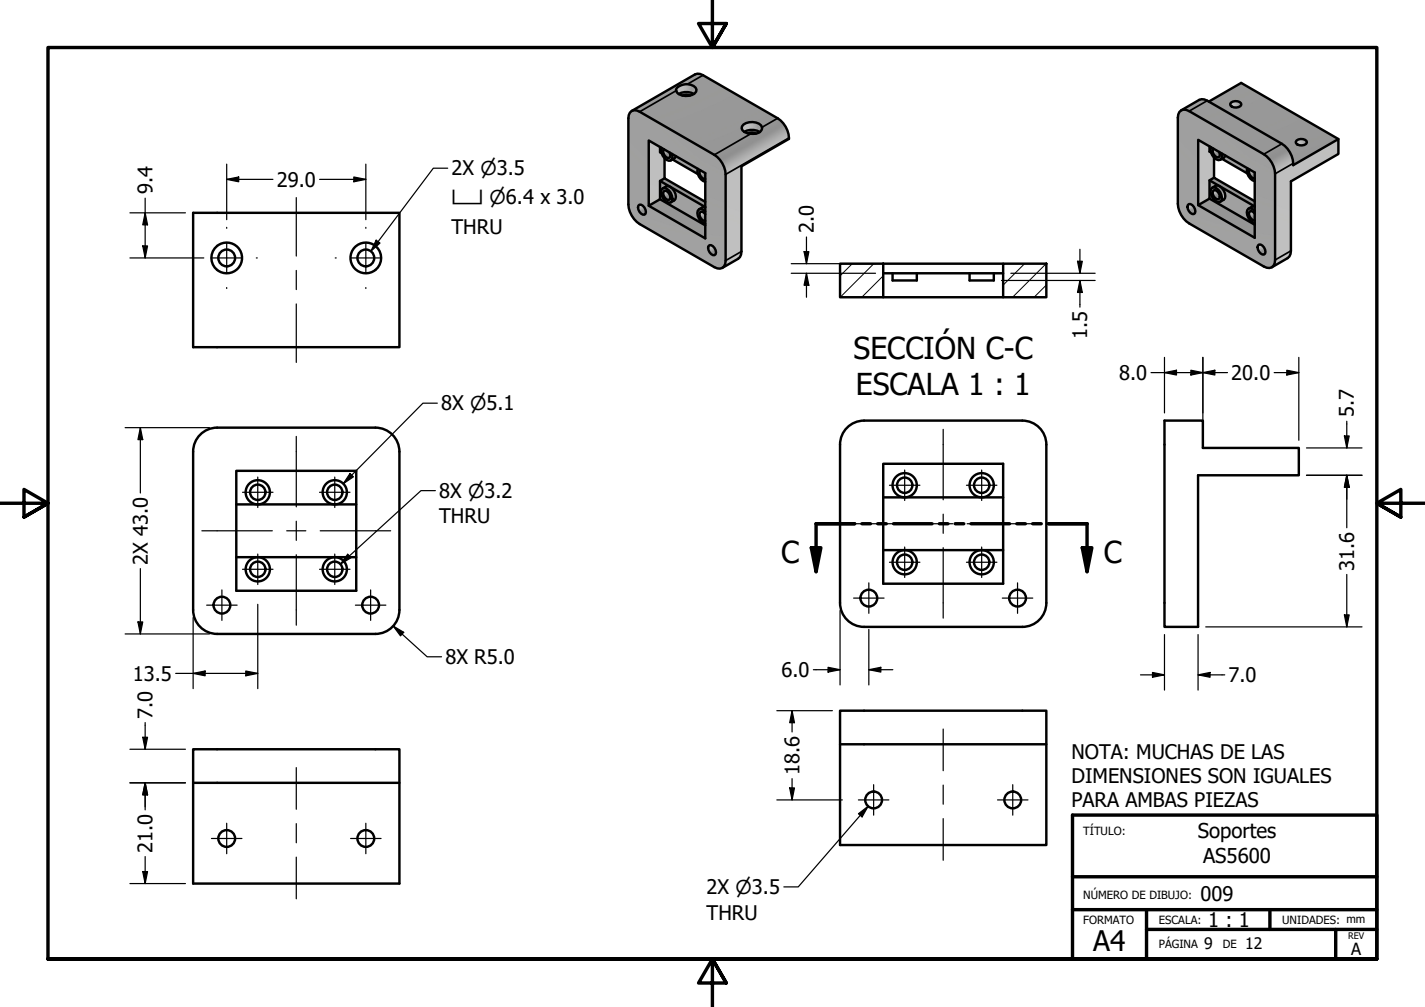
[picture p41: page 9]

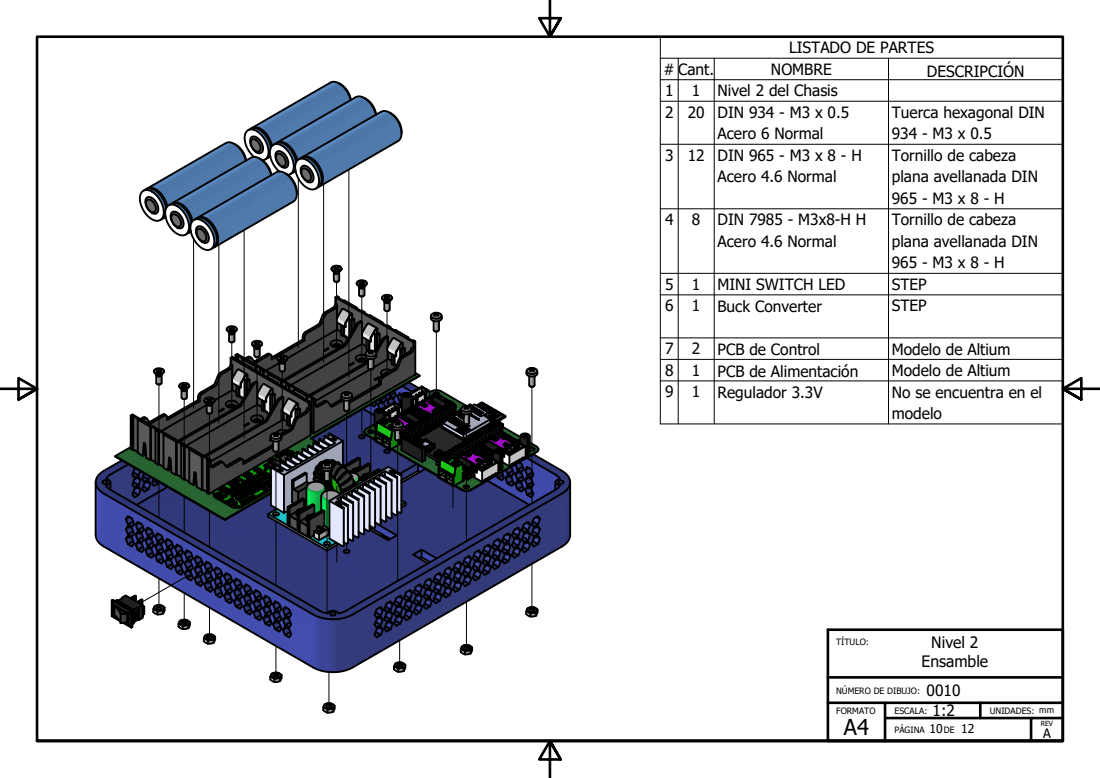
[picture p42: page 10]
# Cant.; NOMBRE; DESCRIPCIÓN; 1 Nivel 2 del Chasis; DIN 934 - M3 x 0.5 Acero 6 Normal; DIN 965 - M3 x 8 - H Acero 4.6 Normal; DIN 7985 - M3x8-H H Acero 4.6 Normal; 1 MINI SWITCH LED; STEP; 1 Buck Converter; 2 PCB de Control; Modelo de Altium; 1 PCB de Alimentación; 1 Regulador 3.3V; TÍTULO:; Nivel 2

LISTADO DE PARTES

Tuerca hexagonal DIN
Tornillo de cabeza
plana avellanada DIN

No se encuentra en el
modelo

NÚMERO DE DIBUJO:

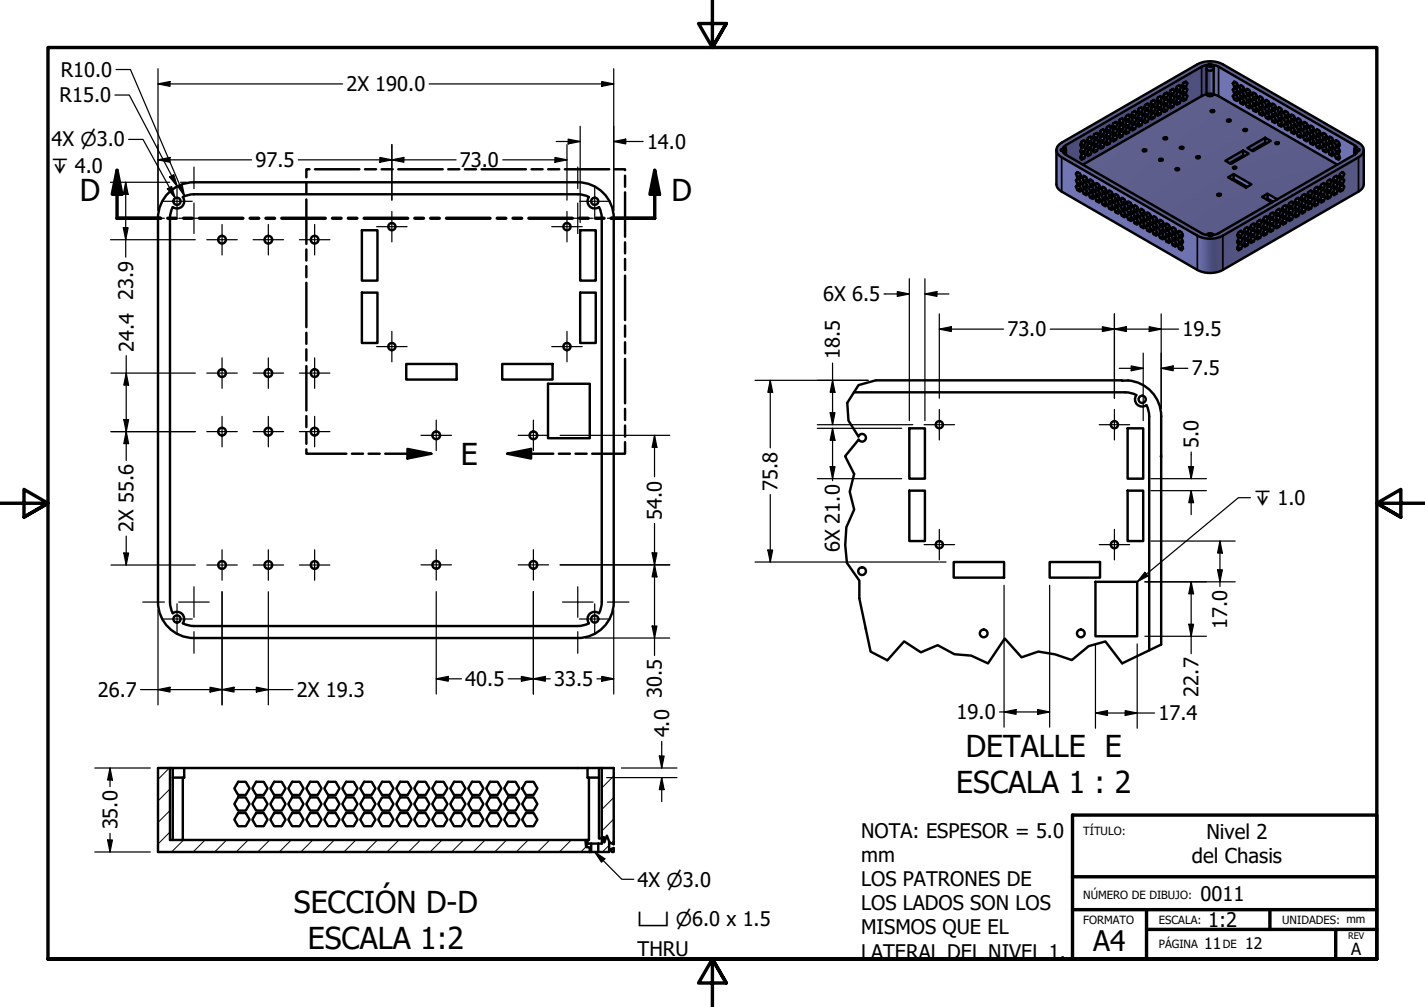
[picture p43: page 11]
SECCIÓN D-D ESCALA 1:2; DETALLE E ESCALA 1 : 2; TÍTULO:; Nivel 2; del Chasis

NOTA: ESPESOR = 5.0
LOS PATRONES DE
LOS LADOS SON LOS
MISMOS QUE EL
LATERAL DEL NIVEL 1.

NÚMERO DE DIBUJO:

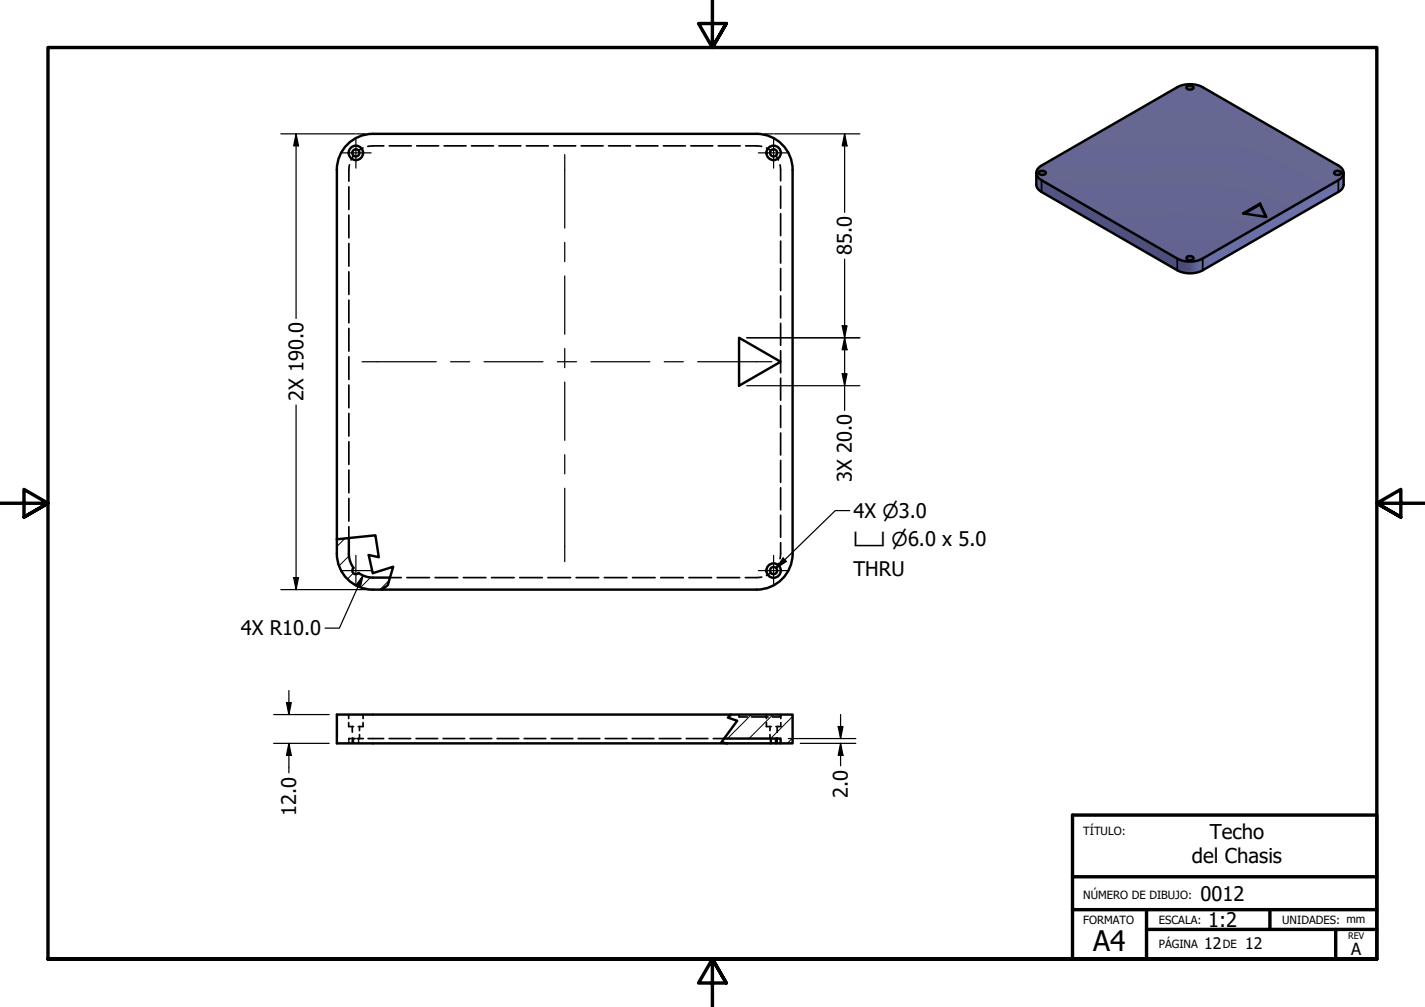
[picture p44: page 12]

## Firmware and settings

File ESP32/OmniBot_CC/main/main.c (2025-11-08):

// Project name: Robotat Omnidirectional Agent (OmniBotCC)
/**
 * @file main.c
 * @brief Main application entry point for ESP-IDF project. Initializes
 * peripherals, configures Wi-Fi, ADC, GPIOs, timers, and handles command
 * parsing and control loop. Uses PID for closed-loop control of stepper motors
 * with AS5600 encoders.
 * @note This project is part of a graduation thesis focusing on control of an
 * omnidirectional robotic agent using a ESP32 microcontroller, inside the
 * Robotat ecosystem of Universidad del Valle de Guatemala. The agent controls
 * four stepper motors to move in a 2D plane, and uses UDP for communication
 * with the Robotat ecosystem.
 * @note The stepper motors are controlled using timers to achieve precise
 * movement and speed control. Also, the stepper motors are equipped with AS5600
 * encoders to measure their position and calculate speed (closed Loop PID 
 * control).
 * @note This project uses the C17 language standard version.
 * @author Christian Campos
 * @date 2025
 * @version 1.0
 */
/* Max line length: 80 characters.
 * Ensure each source line does not exceed 80 chars.
 */
//------------------------------------------------------------------------------
//------------------------------External Libraries------------------------------

#include "freertos/FreeRTOS.h" // FreeRTOS (for tasks and timers)
#include "freertos/task.h"     // FreeRTOS library (for tasks)
#include "driver/gpio.h"       // GPIO library (for pin configuration)
#include "driver/uart.h"       // UART library (for serial communication)
#include "driver/timer.h"      // Timer library (for handling timers)
#include "esp_log.h"           // Logging library (for debug messages)
#include "nvs_flash.h"
#include "esp_err.h"

//------------------------------Standard C libraries----------------------------

#include <string.h> // String library (for handling strings)
#include <stdlib.h> // Standard library (for conversion and memory management)
#include <stdint.h> // Fixed-width integer types

//------------------------------ESP-IDF Libraries-------------------------------
// ESP_Timer libraries
#include <stdio.h>     // Standard input/output library (for printf and similar)
#include <unistd.h>    // Unix library (for sleep and other POSIX functions)
#include "esp_timer.h" // ESP-IDF timer library (for high-resolution timers)
#include "esp_sleep.h" // ESP-IDF deep sleep library (for low power mode)
#include "sdkconfig.h" // ESP-IDF SDK configuration (for project configuration)

// ADC libraries
#include "driver/adc.h" // ADC library (for ADC converter handling)

//------------------------------Custom Libraries--------------------------------
// #include "gpio_stepper_motor.h" // GPIO configuration for steppers 
#include "quad_stepper_control.h" // Library for stepper motor control
#include "udp_wifi.h"             // Library for WiFi configuration 
#include "as5600.h"               // Library for AS5600 encoder handling
// static const char *TAG = "TIMER_STEPPER"; // TAG name for logging

#define CONFIG_ESP_TIMER_TASK_AFFINITY 1 // CPU core affinity for ESP timer task
//-------------------------------Pin Definitions--------------------------------

// quad_stepper_control pins
// Stepper motors
// MS1,MS2,MS3
const gpio_num_t ms_pins[3] = {GPIO_NUM_NC, GPIO_NUM_NC, GPIO_NUM_NC};
//MS1, MS2 and MS3 not used (Set to 32 microstepping directly)
//Enable pin (shared for all motors)
const gpio_num_t enable_pin=GPIO_NUM_23; // Pin to enable/disable all motors
// Motor pins
const gpio_num_t step_pins[4] = {
    GPIO_NUM_26, GPIO_NUM_19, GPIO_NUM_16, GPIO_NUM_14};
const gpio_num_t dir_pins[4] = {
    GPIO_NUM_25, GPIO_NUM_18, GPIO_NUM_4, GPIO_NUM_27};
// AS5600 pins (ADC channels for reading angles)
// ADC1 channels for AS5600 encoders
const gpio_num_t as5600_pins[4] = {
    GPIO_NUM_34, GPIO_NUM_35, GPIO_NUM_32, GPIO_NUM_33};
const adc1_channel_t channels[4] = {
    ADC1_CHANNEL_6, // GPIO34
    ADC1_CHANNEL_7, // GPIO35
    ADC1_CHANNEL_4, // GPIO32
    ADC1_CHANNEL_5  // GPIO33
};
// STEP and DIR pin configuration for 4 motors
// Pins 32-33 motor 0
// Pins 19-18 motor 1
// Pins 27-14 motor 2
// Pins 16-4  motor 3

//---------------------------Parameters and Variables---------------------------
// Wifi
const uint16_t udp_port = 12345;         // UDP port for receiving commands
const gpio_num_t led_wifi = GPIO_NUM_2; // LED pin to indicate WiFi status

// quad_stepper_control parameters and variables
//  Motor parameters
const uint16_t steps_per_rev_base = 200; // Steps per revolution (Datasheet)
const uint16_t rpm_max = 400; // Maximum allowed RPM for the motors

// Volatile variables for motor control
//(this variables are shared between tasks and ISR)
volatile uint8_t microstepping = 32;         // ustepping level 
volatile uint16_t rpm[4] = {10, 10, 10, 10}; // Rotation speed in RPM
volatile float rpm_error[4] = {0, 0, 0, 0};  // Error in RPM
volatile bool direction_cw[4] = {true, false, false, true};
// Rotation direction for each motor (true = CW, false = CCW)
volatile bool active_motors[4] = {false, false, false, false};
// Motor state (active or not)

// PID control variables and parameters (for speed control with AS5600)
const int32_t esp_timer_period_us = 50000; // Timer period in microseconds
// 50000 us = 50 ms = 20 Hz (20 times per second)
const uint8_t samples = 15;             // Number of samples to average
volatile float last_angle[4] = {0.00f}; // Previous angle per motor
// volatile int64_t last_time_us[4] = {0};
volatile uint8_t print_counter = 0; // Counter to print every 2s
volatile float integral_error[4] = {0.00f};
volatile float prev_error[4] = {0.00f};

// PID parameters (tuning required)
volatile float Kp = 0.04;
volatile float Ki = 0.002;
volatile float Kd = 0.0002;
TaskHandle_t hMotorControlTaskHandle = NULL;
// New task for PID
TaskHandle_t hPIDTaskHandle = NULL;

static const char *TAG = "APP_MAIN";

//-------------------------Structures and Definitions---------------------------

//--------------------------------Command Queue---------------------------------
#define CMD_QUEUE_LENGTH 10
#define CMD_BUFFER_SIZE 128
static QueueHandle_t command_queue;

//---------------------------Functions Declaration------------------------------
static void
periodic_timer_callback(void *arg); // Forward declaration

static void
pid_task(void *arg); // Forward declaration

static void
process_command(const char *buf); // Forward declaration

void my_message_handler(const uint8_t *data, uint32_t len,
                        const struct sockaddr *src_addr,
                        void *arg); // Forward declaration

//----------------------------Auxiliary Functions-------------------------------

void init(void)
{
    // GPIO configuration (Dir, Step and MS)
    if (quad_stepper_gpio_setup(dir_pins, step_pins, ms_pins, direction_cw,
                                microstepping) != ESP_OK)
    {
        ESP_LOGE(TAG, "Pin configuration failed");
    }
    else
    {
        ESP_LOGI(TAG, "Pins configured correctly");
    }

    // Initialize NVS
    esp_err_t ret = nvs_flash_init();
    if ((ret == ESP_ERR_NVS_NO_FREE_PAGES) ||
        (ret == ESP_ERR_NVS_NEW_VERSION_FOUND))
    {
        ESP_ERROR_CHECK(nvs_flash_erase());
        ret = nvs_flash_init();
    }
    ESP_ERROR_CHECK(ret);
    // Connect to WiFi (with static IP and LED on)
    udp_connect_wifi(true, true);
    // Start UDP server with my handler
    udp_server_init(my_message_handler, NULL);

    // Timer configuration for each motor

    quad_stepper_init(); // Initialize the motor timers

    // Initialize the ESP_TIMER
    const esp_timer_create_args_t periodic_timer_args = {
        .callback = &periodic_timer_callback,
        .name = "AS5600_Timer",
    };

    esp_timer_handle_t periodic_timer;
    ESP_ERROR_CHECK(esp_timer_create(&periodic_timer_args, &periodic_timer));

    /* Start the timers */
    ESP_ERROR_CHECK(esp_timer_start_periodic(periodic_timer, 
        esp_timer_period_us));

    // AS5600 ADC configuration
    for (int32_t i = 0; i < 4; i++)
    {
        gpio_reset_pin(as5600_pins[i]);
        gpio_set_direction(as5600_pins[i], GPIO_MODE_INPUT);
        as5600_adc_init(channels[i]);
        last_angle[i] = as5600_read_adc(channels[i], samples);
        
    }
    gpio_set_level(enable_pin, 1); // All motors disable (active low)
    // Create PID task
    xTaskCreatePinnedToCore(pid_task, "pid_task", 4096,
                            NULL, 6, &hPIDTaskHandle, 1);
}

// periodic_timer_callback: calculates RPM and notifies PID task
static void
periodic_timer_callback(void *arg)
{
    (void)arg;
    static const float Ts = esp_timer_period_us / 1000000.0f; // in seconds
    static const int32_t printing = 1000000 / esp_timer_period_us; // every 1s
    for (int32_t i = 0; i < 4; i++)
    {
        if (active_motors[i] && rpm[i] > 0)
        {
            // 1) Read the angle from the AS5600 encoder
            float current_angle = as5600_read_adc(channels[i], samples);

            // Determine if both angles are inside the "valid" window [20, 270]
            bool last_in_window = 
            (last_angle[i] >= 20.0f) && (last_angle[i] <= 270.0f);
            bool curr_in_window = 
            (current_angle >= 20.0f) && (current_angle <= 270.0f);

            if (last_in_window && curr_in_window)
            {
                // 2) "Signed" calculation according to direction:
                //    CW: Δ = current - last
                //   CCW: Δ = last    - current
                float delta = direction_cw[i]
                                  ? (current_angle - last_angle[i])
                                  : (last_angle[i] - current_angle);

                if (delta < 0.0f)
                {
                    delta += 360.0f;
                }

                float rpm_calculated = 0.0f;
                if (Ts > 0.0f)
                {
                    rpm_calculated = (delta / 360.0f) * (60.0f / Ts);
                }
                else
                {
                    rpm_calculated = 0.0f;
                }

                if (!(rpm_calculated >= 0.0f))
                {
                    rpm_calculated = 0.0f;
                }
                else if (rpm_calculated > 1.25f * (float)rpm[i])
                {
                    rpm_calculated = 1.25f * (float)rpm[i];
                }
                else if (rpm_calculated < 0.75f * (float)rpm[i])
                {
                    rpm_calculated = 0.75f * (float)rpm[i];
                }

                // Store measured RPM for PID task
                rpm_error[i] = rpm_calculated;

                // Print info every "printing" cycles (disabled by default)
                #if 0
                if (print_counter >= (uint8_t)(printing - 1))
                {
                    ESP_LOGI(TAG,
                             "Motor %d: CurrentAngle: %.2f°, δθ=%.2f°, 
                             Ts=%.3fs, RPM_obj=%d, RPM_med=%.2f (calculated)",
                             (int)i, current_angle, delta, Ts, (int)rpm[i], 
                             rpm_calculated);
                }
                #endif
            }
            else
            {
                rpm_error[i] = 0.0f;
                #if 0
                if (print_counter >= (uint8_t)(printing - 1))
                {
                    ESP_LOGI(TAG, 
                    "Motor %d: RPM skipped (angles out of [20,270]). last=%.2f°
                    , curr=%.2f°", (int)i, last_angle[i], current_angle);
                }
                #endif
            }
            last_angle[i] = current_angle;
        }
    }

    print_counter++;
    if (print_counter >= (uint8_t)printing)
    {
        print_counter = 0;
    }

    // Notifies the PID task
    xTaskNotifyGive(hPIDTaskHandle);
}



static void
pid_task(void *arg)
{
    static const float Ts = esp_timer_period_us / 1000000.0f; // in seconds
    while (1)
    {
        // Wait for notification from timer callback
        ulTaskNotifyTake(pdTRUE, portMAX_DELAY); 

        for (int32_t i = 0; i < 4; i++)
        {
            if (active_motors[i] && rpm[i] > 0)
            {
                float rpm_calculated = rpm_error[i]; 
                float error = rpm[i] - rpm_calculated;
                float P = Kp * error;

                // Anti-windup: Clamp integral_error[i] to avoid excessive 
                //accumulation
                integral_error[i] += error * Ts;
                if (integral_error[i] > 1.5 * rpm[i]) 
                {
                    integral_error[i] = 1.5 * rpm[i];
                }
                else if (integral_error[i] < -1.5 * rpm[i]) 
                {
                    integral_error[i] = -1.5 * rpm[i];
                }

                float derivative = 0.0f;
                if (Ts > 0.0f)
                {
                    derivative = (error - prev_error[i]) / Ts;
                }

                prev_error[i] = error;

                float control_signal = 
                P + Ki * integral_error[i] + Kd * derivative;

                if ((control_signal < (0.05f * rpm[i])) && 
                (control_signal > -(0.05f * rpm[i])))
                {
                    control_signal = 0.0f;
                }

                // rpm_error now stores the control signal for the motor
                // control task
                rpm_error[i] = control_signal;
            }
            else
            {
                rpm_error[i] = 0.0f;
            }
        }

        // Notifies the motor control task
        xTaskNotifyGive(hMotorControlTaskHandle);
    }
}

static void
process_command(const char *buf)
{
    ESP_LOGI(TAG, "Command received: %s", buf);

    #if 0
    if (strncmp(buf, "step=", 5) == 0)
    {
        int32_t mode = atoi(buf + 5);
        if ((mode == 8) || (mode == 32))
        {
            microstepping = (uint8_t)mode;
            ESP_LOGI(TAG, "Setting microstepping to: %d", (int)microstepping);
        }
        else
        {
            ESP_LOGW(TAG, "Invalid microstepping: %d", (int)mode);
        }
    }
    #endif
    
    if (strcmp(buf, "start") == 0)
    {
        for (int32_t i = 0; i < 4; i++)
        {
            active_motors[i] = true;
            gpio_set_level(enable_pin, 0);
            // update_timer_interval(i);
        }
        ESP_LOGI(TAG, "All motors started");
    }
    else if (strcmp(buf, "stop") == 0)
    {
        for (int32_t i = 0; i < 4; i++)
        {
            active_motors[i] = false;
            gpio_set_level(enable_pin, 1);
            // update_timer_interval(i);
        }
        ESP_LOGI(TAG, "All motors stopped");
    }   
    else
    {
        for (int32_t i = 0; i < 4; i++)
        {
            char prefix[16];
            snprintf(prefix, sizeof(prefix), "m%d_rpm=", (int)i);
            if (strncmp(buf, prefix, strlen(prefix)) == 0)
            {
                int32_t value = atoi(buf + strlen(prefix));
                if (value < 0)
                {
                    value = 0;
                }
                if (value > rpm_max)
                {
                    ESP_LOGW(TAG, "RPM exceeds limit (%d): %d", 
                        (int)rpm_max, (int)value);
                    value = rpm_max;
                }
                rpm[i] = (uint16_t)value;
                ESP_LOGI(TAG, "Motor %d RPM updated to: %d", 
                    (int)i, (int)rpm[i]);
                // update_timer_interval(i);
                break;
            }
            snprintf(prefix, sizeof(prefix), "m%d_dir=", (int)i);
            if (strncmp(buf, prefix, strlen(prefix)) == 0)
            {
                const char *d = buf + strlen(prefix);
                if (strcasecmp(d, "CW") == 0)
                {
                    direction_cw[i] = true;
                    // gpio_set_level(dir_pins[i], 0);
                    ESP_LOGI(TAG, "Motor %d direction: CW", (int)i);
                }
                else if (strcasecmp(d, "CCW") == 0)
                {
                    direction_cw[i] = false;
                    // gpio_set_level(dir_pins[i], 1);
                    ESP_LOGI(TAG, "Motor %d direction: CCW", (int)i);
                }
                else
                {
                    ESP_LOGW(TAG, "Invalid direction for motor %d: %s", 
                        (int)i, d);
                }
                break;
            }
            snprintf(prefix, sizeof(prefix), "m%d_start", (int)i);
            if (strcmp(buf, prefix) == 0)
            {
                active_motors[i] = true;
                // update_timer_interval(i);
                ESP_LOGI(TAG, "Motor %d started", (int)i);
                break;
            }
            snprintf(prefix, sizeof(prefix), "m%d_stop", (int)i);
            if (strcmp(buf, prefix) == 0)
            {
                active_motors[i] = false;
                // update_timer_interval(i);
                ESP_LOGI(TAG, "Motor %d stopped", (int)i);
                break;
            }
        }
    }
    if (hMotorControlTaskHandle != NULL)
    {
        xTaskNotifyGive(hMotorControlTaskHandle);
    }
}


// This function is called when a message is received via UDP
void my_message_handler(const uint8_t *data, uint32_t len,
                        const struct sockaddr *src_addr,
                        void *arg)
{
    char buf[128];
    if (len >= (int32_t)sizeof(buf))
        len = (int32_t)sizeof(buf) - 1;
    memcpy(buf, data, len);
    buf[len] = '\0';
    process_command(buf);
}

//---------------------------------Interrupts-----------------------------------

//-----------------------------------Tasks--------------------------------------

//Uncomment this function if UART task is needed
#if 0
void 
uart_task(void *arg)
{
    char buf[128];
    int32_t idx = 0;
    while (1)
    {
        uint8_t c;
        int32_t len = uart_read_bytes(UART_NUM_0, &c, 1, pdMS_TO_TICKS(10));
        if (len > 0)
        {
            if ((c == '\n') || (c == '\r'))
            {
                if (idx > 0)
                {
                    buf[idx] = '\0';
                    process_command(buf);
                    idx = 0;
                }
            }
            else if (idx < (int32_t)sizeof(buf) - 1)
            {
                buf[idx++] = c;
            }
        }
    }
}
#endif
//-------------------------------Main Function----------------------------------
void app_main(void)
{
    init(); 
    // System startup message
    ESP_LOGI(TAG, "System initialized. Waiting for commands...");
}

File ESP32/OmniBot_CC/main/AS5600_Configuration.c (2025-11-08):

/*
 * as5600_idf_config.c
 * Interactive AS5600 configuration and monitor for ESP-IDF
 * Runs entirely on default UART0 (use `idf.py monitor` to interact).
 *
 * Uses the as5600 component (as5600.h / as5600.c) you provided that
 * implements: as5600_i2c_init(...), as5600_adc_init(...),
 * as5600_read_adc(...), read_raw_angle(...), read_zmco_register(...),
 * read_status_register(...), read_conf_register(...), read_mang_register(...),
 * read_zpos_register(...), write_burn_register(...), write_conf_register(...),
 * write_mang_register(...), write_zpos_register(...).
 *
 * Place this file under `main/` (or a component) and add to CMakeLists.txt.
 * Build with `idf.py build` and run `idf.py monitor` to interact.
 *
 * Author: ChatGPT (adapted for Christian Campos project)
 * Date: 2025
 */

#define BURN_SETTING_CMD 0x40
#define BURN_ANGLE_CMD 0x80
#include <stdio.h>
#include <stdlib.h>
#include <string.h>
#include <ctype.h>

#include "freertos/FreeRTOS.h"
#include "freertos/task.h"
#include "esp_log.h"
#include "esp_err.h"
#include "driver/uart.h"
#include "driver/adc.h"
#include "esp_vfs_dev.h"  

#include "as5600.h" 

static const char *TAG = "AS5600_CFG";

// Change this if your analog input uses a different ADC channel
#ifndef AS5600_ADC_CHANNEL
#define AS5600_ADC_CHANNEL ADC1_CHANNEL_4 // GPIO32 by default; change if needed
#endif

#define UART_RX_TIMEOUT_MS 10000

//---------------------------Functions Declaration------------------------------
static void
periodic_timer_callback(void *arg); // Forward declaration

// I2C handles (created by as5600_i2c_init)
static i2c_master_bus_handle_t i2c_bus = NULL;
static i2c_master_dev_handle_t as5600_dev = NULL;



// UART helpers: read a single non-whitespace char with optional timeout (ms).
// Returns -1 on timeout.
static int 
uart_read_char(uint32_t timeout_ms)
{
    uint8_t ch;
    int len = uart_read_bytes(UART_NUM_0, &ch, 1, pdMS_TO_TICKS(timeout_ms));
    if (len <= 0)
        return -1;
    return (int)ch;
}

// waitForYes: prints msg and waits for Y/S or N. timeout_ms==0 -> wait forever.
static bool 
waitForYes(const char *msg, uint32_t timeout_ms)
{
    printf("%s (Y/N): ", msg);
    fflush(stdout);

    uint32_t start = xTaskGetTickCount();
    while (1)
    {
        int c = uart_read_char(100);
        if (c > 0)
        {
            // skip whitespace
            while (isspace((unsigned char)c))
            {
                c = uart_read_char(100);
                if (c < 0)
                    break;
            }
            if (c < 0)
                continue; // got only whitespace
            char ch = (char)c;
            ch = toupper((unsigned char)ch);

            // flush rest of the line
            uint8_t tmp;
            while (uart_read_bytes(UART_NUM_0, &tmp, 1, pdMS_TO_TICKS(10)) > 0)
            {
                if (tmp == '\n') break;
            }

            if (ch == 'Y' || ch == 'S')
            {
                printf("%c\n", ch);
                return true;
            }
            else if (ch == 'N')
            {
                printf("%c\n", ch);
                return false;
            }
            else
            {
                printf("\nRespuesta no válida. Ingrese Y (sí) o N (no): ");
            }
        }

        if (timeout_ms > 0)
        {
            uint32_t now = xTaskGetTickCount();
            if ((now - start) >= pdMS_TO_TICKS(timeout_ms))
            {
                printf("\nTiempo de espera agotado.\n");
                return false;
            }
        }
        vTaskDelay(pdMS_TO_TICKS(10));
    }
}

// The interactive configuration task 
static void interactive_config_task(void *arg)
{
    (void)arg;

    ESP_LOGI(TAG, "Starting AS5600 interactive configuration over UART0");

    // Initialize I2C using the helper in your as5600.c
    as5600_i2c_init(&i2c_bus, &as5600_dev);

    // Initialize ADC channel used for the analog reading
    as5600_adc_init(AS5600_ADC_CHANNEL);

    vTaskDelay(pdMS_TO_TICKS(100));

    printf("\n=== Configuración AS5600 paso a paso (ESP-IDF) ===\n");
    printf("ATENCIÓN: Las operaciones BURN son irreversibles. "
           "Proceda con cuidado.\n\n");

    if (!waitForYes("¿Desea configurar el AS5600?", 15000))
    {
        printf("Se ha elegido no configurar el AS5600 (o timeout). "
               "Saltando configuración.\n\n");
        // fall through to the monitoring loop
    }
    else
    {
        uint8_t zmco = 0;

        // Paso 2: Leer STATUS_REG
        if (waitForYes("2) Leer STATUS_REG", 0))
        {
            vTaskDelay(pdMS_TO_TICKS(100));
            uint8_t status = read_status_register(as5600_dev);
            if (status == 0xFF)
            {
                printf("Error leyendo STATUS_REG (I2C).\n");
            }
            else
            {
                bool md = (status & (1 << 5));
                printf("MD (magnet detect): %s\n", md ? "OK" : "NO DETECTADO");
                while (!md)
                {
                    printf("Coloca un imán adecuado y confirma nuevamente.\n");
                    while (!waitForYes("¿Seguir?", 0))
                    {
                        printf("   Esperando confirmación para continuar...\n");
                        vTaskDelay(pdMS_TO_TICKS(500));
                    }
                    status = read_status_register(as5600_dev);
                    if (status == 0xFF)
                    {
                        printf("Error leyendo STATUS_REG (I2C). 
                            Abortando paso.\n");
                        break;
                    }
                    md = (status & (1 << 5));
                    printf("MD (magnet detect): %s\n", 
                        md ? "OK" : "NO DETECTADO");
                }
            }
        }
        else
        {
            printf("Paso 2 saltado.\n");
        }

        // Paso 3: Leer ZMCO
        if (waitForYes("3) Leer ZMCO (veces BURN_ANGLE)", 0))
        {
            vTaskDelay(pdMS_TO_TICKS(100));
            uint8_t r = read_zmco_register(as5600_dev);
            if (r == 0xFF)
            {
                printf("Error leyendo ZMCO (I2C).\n");
            }
            else
            {
                zmco = r & 0x03;
                printf("ZMCO = %u\n", (unsigned)zmco);
            }
        }
        else
        {
            printf("Paso 3 saltado.\n");
        }
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

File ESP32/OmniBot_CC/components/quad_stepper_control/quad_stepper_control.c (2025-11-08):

/**
 * @file quad_stepper_control.c
 * @author Christian Campos (cam21760@uvg.com.gt)
 * @brief Library for configuring and controlling 4 stepper motor with DRV8825 
 * using ESP-IDF. The stepper motors are controlled using hardware timers
 * to achieve precise movement and speed control.
 * @version 1.0
 * @date 2025
 *
 * @copyright Copyright (c) 2025
 *
 */

//------------------------------External Libraries------------------------------
#include "driver/timer.h"
#include "driver/gpio.h"
#include "esp_err.h"
#include "freertos/FreeRTOS.h"
#include "freertos/task.h"
#include "esp_log.h"
//----------------------------Custom Libraries----------------------------------
#include "quad_stepper_control.h" // Library to handle stepper motor timers 

//------------------------------External Variables------------------------------
// These variables must be defined in the main code main.c and here as externs:
// Fixed variables
extern const gpio_num_t enable_pin; // Pin to enable/disable all motors
extern const gpio_num_t step_pins[4]; // STEP pins for 4 motors
extern const gpio_num_t dir_pins[4]; // Direction (DIR) pins for 4 motors 
extern const gpio_num_t ms_pins[3]; // Microstepping pins (MS1, MS2, MS3) 
extern const uint16_t steps_per_rev_base; // Base steps per revolution
// Global Variables
extern volatile uint8_t microstepping; // Microstepping (1, 2, 4, 8, 16, 32)
extern volatile uint16_t rpm[4]; // Rotation speed in RPM for each motor
extern volatile float rpm_error[4]; // Error in RPM for each motor
extern volatile bool active_motors[4]; // Motor state (active or not)
extern volatile bool direction_cw[4]; // Rotation direction for each motor 
extern TaskHandle_t hMotorControlTaskHandle;
// (true = CW, false = CCW) 

//------------------------------Internal Variables------------------------------
// These variables are internal to the timer module and should not be accessed 
// directly from the main code- They are defined here to avoid name conflicts 
// and maintain encapsulation
static uint64_t half_period_us[4] = {0};
static volatile bool  step_state[4]    = {false};
static const char *TAG_TIMER = "TIMER_STEPPER"; //TAG 
//--------------------------Definitions and Structures--------------------------
#define MOTOR_COUNT 4 // Number of motors
#define MICROSTEPPING_PINS 3 // Number of microstepping pins (MS1, MS2, MS3)
static timer_motor_map_t timer_map[4] = {
    { TIMER_GROUP_0, TIMER_0, 0 }, // Map motor 0 to timer 0 of group 0
    { TIMER_GROUP_0, TIMER_1, 1 }, // Map motor 1 to timer 1 of group 0
    { TIMER_GROUP_1, TIMER_0, 2 }, // Map motor 2 to timer 0 of group 1
    { TIMER_GROUP_1, TIMER_1, 3 } // Map motor 3 to timer 1 of group 1
};

//----------------------------Function Prototypes-------------------------------
//Local function prototypes
//Global function prototypes in header file quad_stepper_control.h
/**
 * @brief Task that controls the motors based on the current values of rpms, ms, etc.
 * @details This task runs on core 1 and is notified from other parts of the 
 * code when there are changes in the motor parameters.
 */
static void 
quad_motor_control_task(void *arg);

/**
 * @brief This function configures the GPIO pins to control stepper motors 
 * (MS, DIR, and STEP).
 * 
 * @param arg 
 */
static void 
timer_config_task(void *arg); // Task to configure timers

/**
 * @brief Configures a hardware timer to generate STEP pulses on a motor.
 * 
 * Initializes the timer, registers the ISR, and leaves the timer paused until 
 * the first start.
 * 
 * @param motorIndex Motor index (0–3).
 **/

static void 
configure_timer_for_motor(uint8_t motorIndex);

/**
* @brief This function configures the microstepping pins (MS1, MS2, MS3) 
according to the specified microstepping level. Should be called whenever 
the microstepping level is changed.
Parameters:
* @param ms_pins Array of microstepping pins.
* @param microstepping Microstepping level (1, 2, 4, 8, 16, 32)
* @return ESP_OK if configuration was successful, or an error code otherwise.
*/
static void  
quad_stepper_set_step(const gpio_num_t ms_pins[], uint8_t microstepping);

/**
 * @brief Updates the timer alarm value according to rpm and active state of 
 * the motor.
 * 
 * Pauses the timer, recalculates the half period, and if the motor is active,
 * restarts the timer to emit STEP pulses.
 * 
 * @param motorIndex Motor index (0–3).
 **/
static void 
update_timer_interval(uint8_t motorIndex, float error);

/**
 * @brief Calculates the half period (in µs) for the given motor, 
 * according to rpm and microstepping.
 * 
 * @param motorIndex Motor index (0–3).
 * @return Half period in microseconds, or 0 if rpm≤0.
 **/
static uint64_t 
calculate_half_period_us(uint8_t motorIndex, float error);

/**
 * @brief Timer interrupt service routine (generates toggling of the STEP pin).
 * 
 * @param arg Pointer to the timer→motor mapping structure.
 **/
static void 
IRAM_ATTR timer_isr(void *arg);


//--------------------------------Global Functions------------------------------

void 
quad_stepper_init()
{
    // Create a task to configure the timers on core 1
    xTaskCreatePinnedToCore(timer_config_task,
                            "timer_config_task", 2048, NULL, 5, NULL, 1);
    xTaskCreatePinnedToCore(quad_motor_control_task, "quad_motor_control_task",
        4096, NULL, 5, &hMotorControlTaskHandle, 1);
    // ESP_LOGI(TAG_TIMER, "Timer configuration task created on core 1");
};

esp_err_t
quad_stepper_gpio_setup(const gpio_num_t dir_pins[], 
    const gpio_num_t step_pins[], const gpio_num_t ms_pins[], 
    volatile bool direction_cw[], uint8_t microstepping)
{

    for (int i = 0; i < MICROSTEPPING_PINS; i++)
    {
        // Configure microstepping pins
        //gpio_reset_pin(ms_pins[i]);
        gpio_set_direction(ms_pins[i], GPIO_MODE_OUTPUT);
        // Initialize the microstepping pins to low
        // gpio_set_level(ms_pins[i], 0);
    }
    // Configure microstepping pins (MS1, MS2, MS3)
    //quad_stepper_set_step(ms_pins, microstepping); //Disabled 
    // Configure direction and step pins for 4 motors
    gpio_reset_pin(GPIO_NUM_14); //This PIN is SPI CLK, so we reset it first
    gpio_reset_pin(GPIO_NUM_23);
    for (int i = 0; i < MOTOR_COUNT; i++)
    {
        //gpio_reset_pin(dir_pins[i]);
        //gpio_reset_pin(step_pins[i]);
        // Configure direction and step pins
        gpio_set_direction(dir_pins[i], GPIO_MODE_OUTPUT);
        gpio_set_direction(step_pins[i], GPIO_MODE_OUTPUT);
        // Initialize the pins to low to avoid unwanted movements
        gpio_set_level(dir_pins[i], direction_cw[i] ? 0 : 1);
        gpio_set_level(step_pins[i], 0);
        // configure_timer_for_motor(i);
    }
    gpio_set_direction(enable_pin, GPIO_MODE_OUTPUT);
    //gpio_set_level(enable_pin, 1); // All motors disable (active low)
    // ESP_LOGI(TAG, "GPIO configured successfully");
    return ESP_OK;
}
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

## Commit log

2025-07-17 Agregadas las funciones de Matlab y Python para el robot. Hace falta añadir las funciones de Python para controlar.
2025-07-18 Agregadas las funciones de Python
2025-07-26 Agregado nuevas funciones de lectura y escritura en Matlab y Python
2025-07-28 Solo modifiqué los archivos de Matlab y Python.
    [analog_ESP32_datos.xlsx]
2025-07-31 Agregue el archivo de configuración del AS5600 En Arduino
2025-08-09 Agregado el proyecto del OmniRobot_CC (ESP32) Agregado la configuracion del Robot con el Robotat
2025-10-10 Changed the logic, so that the microstepping mode setting is disabled (not used) and the motors are always in 32 step mode. Also, added the enable pin to the motor driver connections, changed the wif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
2025-11-08 Added all the finals files for the thesis project, including Matlab and Python functions, and updated the ESP32 code to include a PID control task that calculates control signals for stepper motors b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
    [analog_ESP32_datos.xlsx]
2026-07-05 Change folder name
    [Base_Motor_x4.stl, Eje_Llanta_x4.stl, Nivel1_Base.stl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]
